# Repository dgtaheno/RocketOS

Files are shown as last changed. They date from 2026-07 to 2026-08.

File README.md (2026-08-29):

# RocketOS

ESP32-based flight computer featuring GPS telemetry, barometric altitude estimation, dual temperature sensing, battery monitoring, MAVLink telemetry, autonomous flight event detection, audible event feedback, fault-tolerant SD logging, data-driven flight profile replay testing and serial hardware flight profile replay.

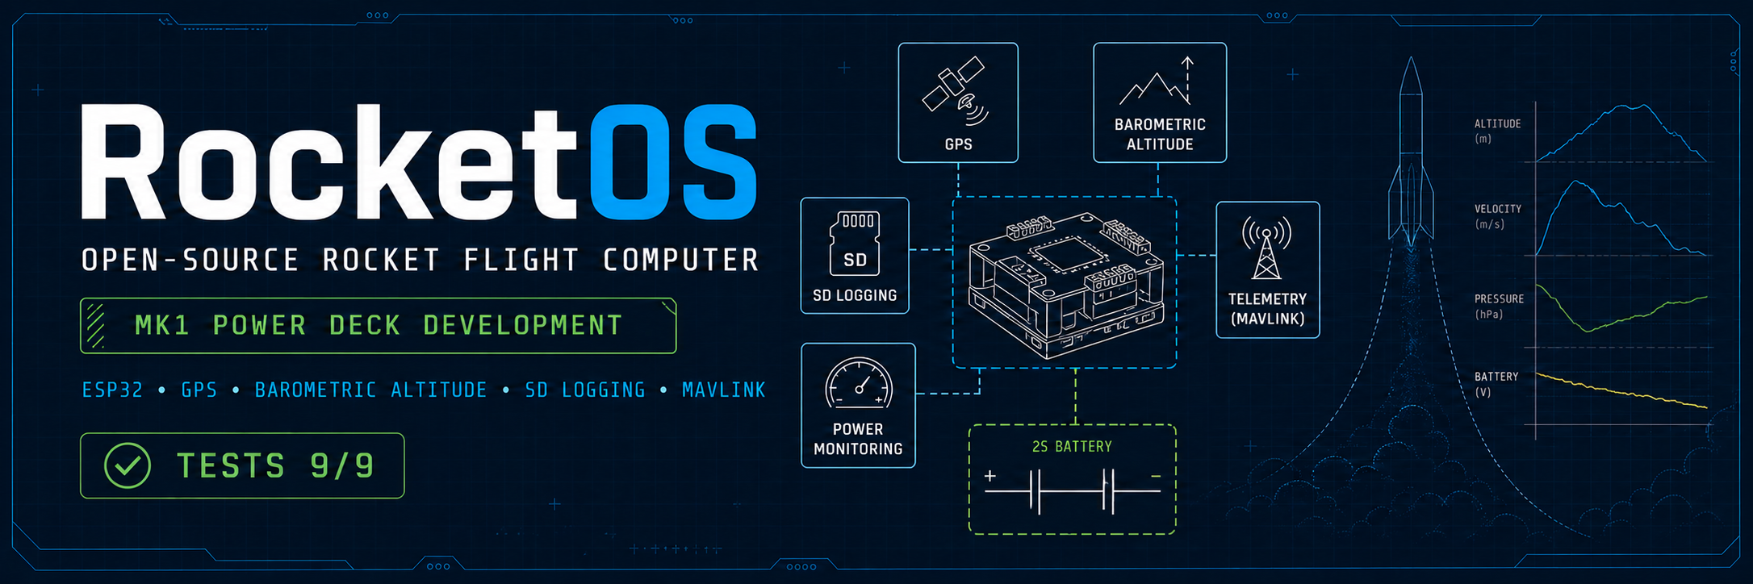
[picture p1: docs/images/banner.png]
Project Banner














---

# Project Status

RocketOS is currently an advanced bench prototype and pre-flight integration platform. The implemented ESP32 DevKitC V4 firmware provides sensing, logging, telemetry, health monitoring, flight-state detection and replay validation.

RocketOS Mk1 targets an ESP32-S3 SuperMini N16R8, a fixed 2S LiPo architecture and a modular deck-based hardware stack for a 54 mm airframe. The Power Deck is under development and has not yet been fabricated or electrically validated.

The current Mk1 development battery is a Tattu 2S 550 mAh LiPo. The firmware BatteryMonitor was migrated from 4S to 2S and bench validated on 2026-08-28.

---

# Real Hardware Prototype

Hardware platform used during validation testing.

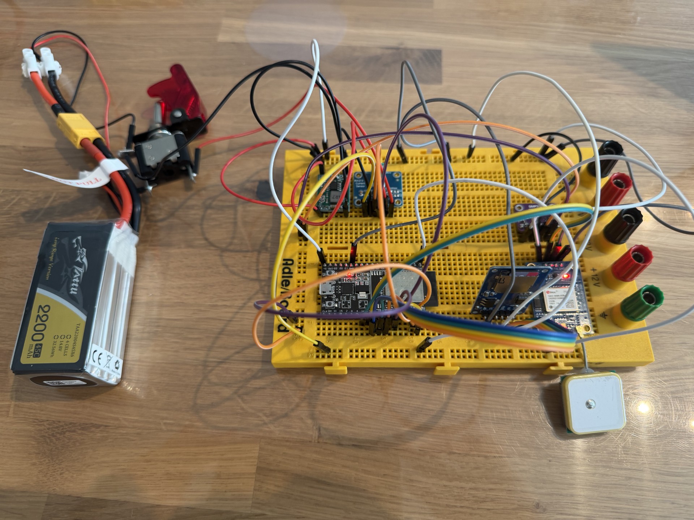
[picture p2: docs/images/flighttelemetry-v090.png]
Flight Telemetry Prototype


---

# Hardware

| Component | Model | Function |
|---|---|---|
| Microcontroller | ESP32 DevKitC V4 | Flight computer |
| GNSS Receiver | u-blox NEO-M9N | Position, altitude, UTC time |
| Barometric Sensor | BMP388 | Pressure, temperature, relative altitude |
| External Thermometer | DS18B20 | Ambient outside temperature |
| Power Monitor | INA219 | Voltage, current, power |
| Storage | MicroSD Module | Flight data logging |
| Audible Feedback | Active Buzzer | Event feedback and recovery beacon |
| Power Supply | MP1584 Buck Converter | Regulated 5 V rail |
| Battery | Tattu LiPo 2S 550 mAh | Current Mk1 development battery |

<table>
  <tr>
    <td align="center"><br><b>NEO-M9N</b></td>
    <td align="center"><br><b>BMP388</b></td>
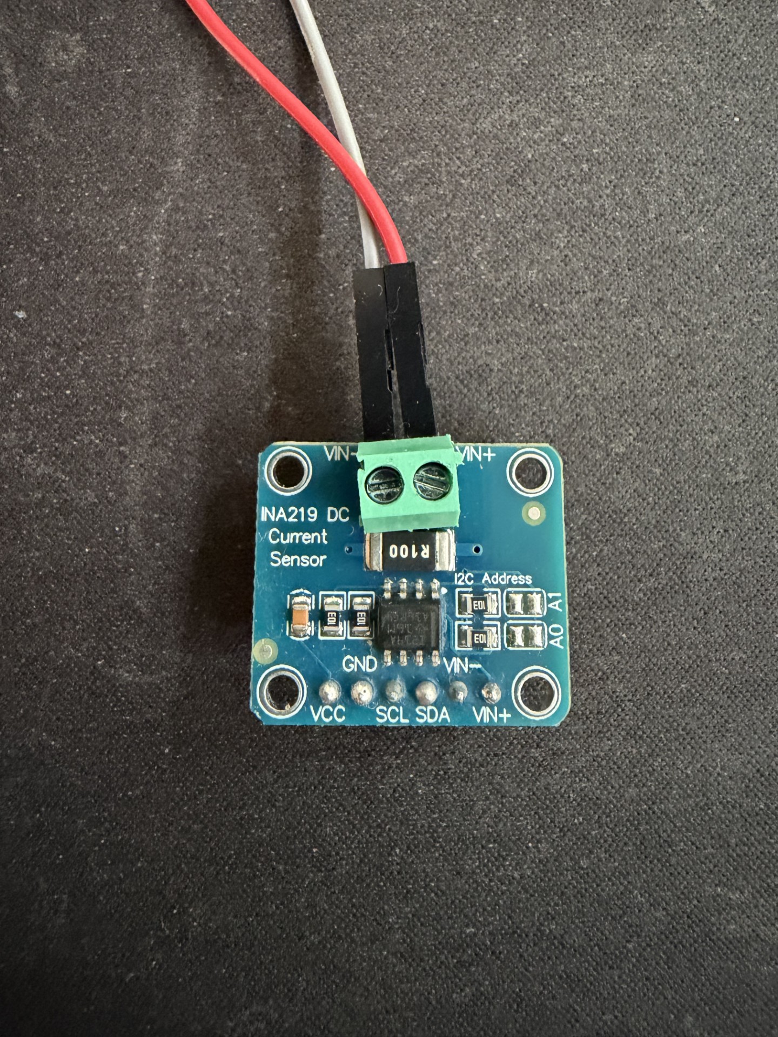
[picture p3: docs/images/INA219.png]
    <td align="center"><br><b>INA219</b></td>
  </tr>
  <tr>
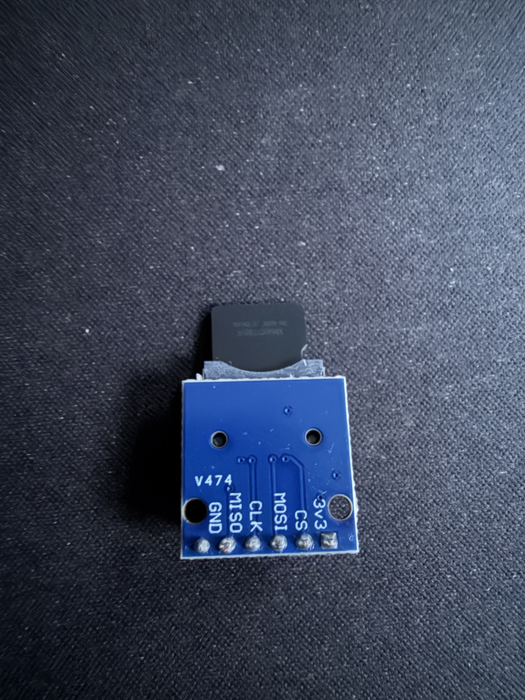
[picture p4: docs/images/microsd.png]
    <td align="center"><br><b>MicroSD</b></td>
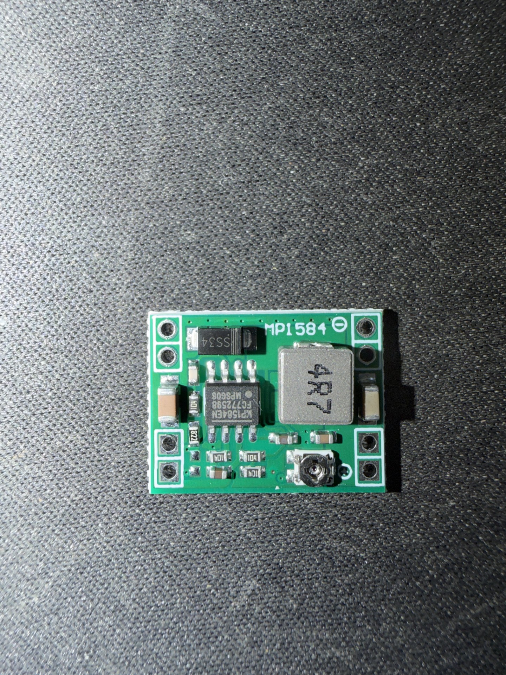
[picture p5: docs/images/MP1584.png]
    <td align="center"><br><b>MP1584</b></td>
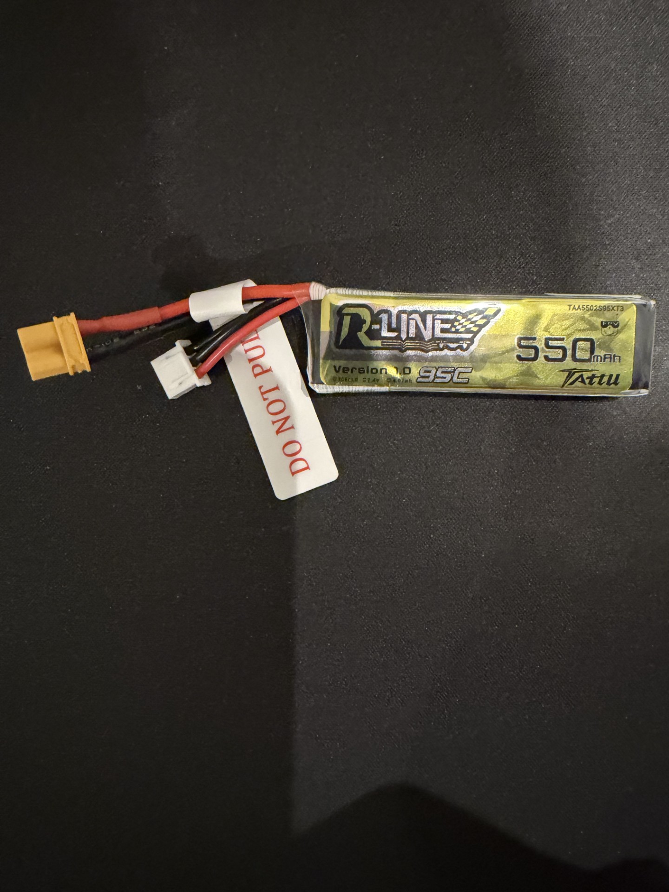
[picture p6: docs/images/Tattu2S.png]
    <td align="center"><br><b>LiPo 2S Tattu 550 mAh</b></td>
  </tr>
  <tr>
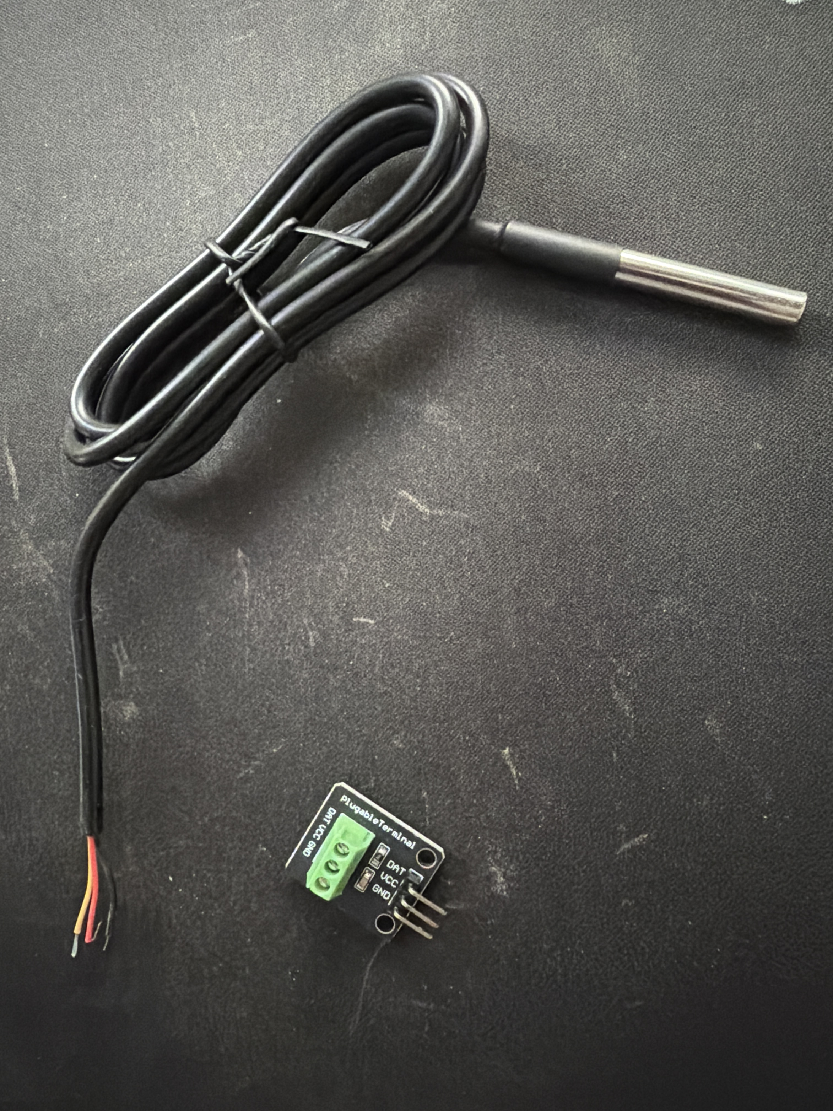
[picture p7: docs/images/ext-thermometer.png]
    <td align="center"><br><b>DS18B20</b></td>
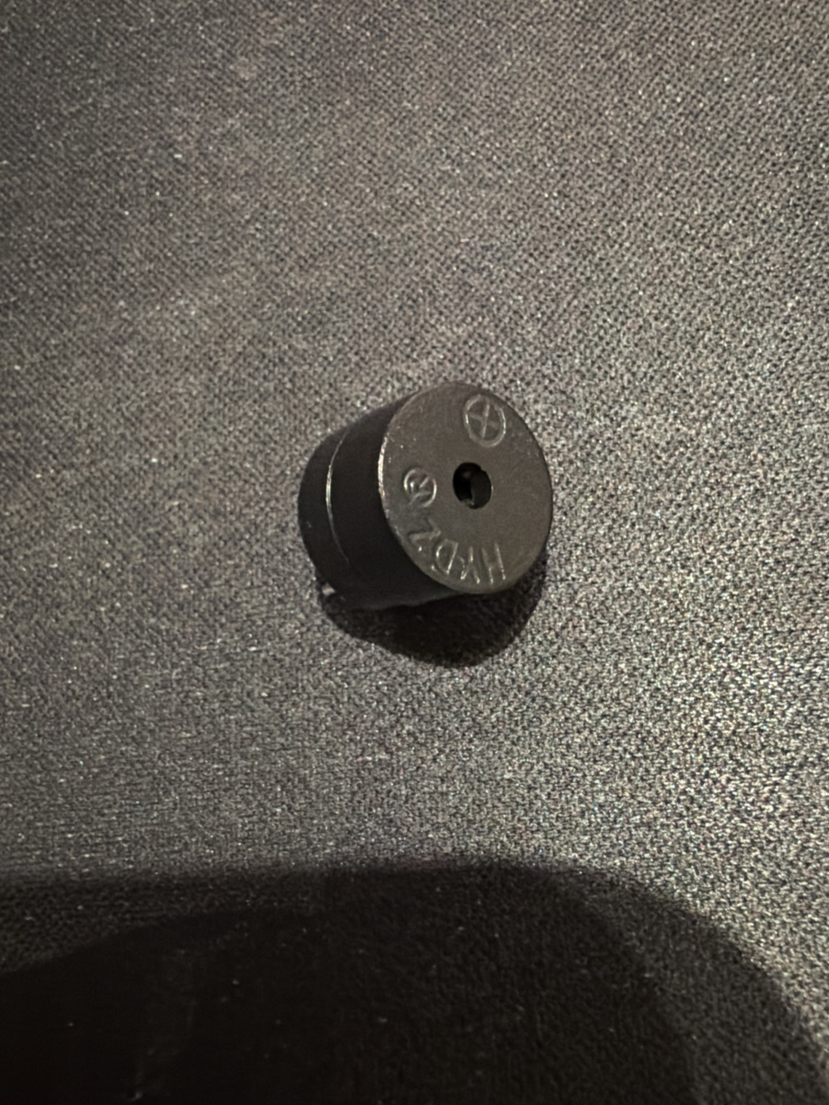
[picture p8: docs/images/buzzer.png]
    <td align="center"><br><b>Active Buzzer</b></td>
    <td></td>
  </tr>
</table>

---

# Overview

RocketOS is a modular open-source flight computer, telemetry, data-logging, validation and post-flight analysis ecosystem for experimental model rocketry.

The project combines:

- GPS telemetry
- Barometric altitude estimation
- Dual temperature sensing with BMP388 and DS18B20
- Battery and power monitoring
- MAVLink telemetry
- QGroundControl interoperability
- Autonomous flight event detection
- Audible event feedback and recovery beacon
- Runtime health monitoring
- Event-driven diagnostics
- Fault-tolerant SD logging
- Buffered telemetry recovery
- Unit tests for core flight logic
- CSV-based flight profile replay tests
- Serial hardware flight profile replay on ESP32
- OpenRocket and generic CSV import tooling

The validation status of each subsystem is documented separately. Flight-profile replay tests run both on the host computer through the PlatformIO native environment and on the ESP32 through USB serial replay. This evidence does not establish that the complete RocketOS Mk1 hardware stack is flight validated.

---

# Scope

This flight computer targets model rocketry.

The flight state machine models a ballistic rocket flight profile with parachute recovery: powered boost, unpowered coast, a single apogee, and descent under recovery. Powered controlled vehicles such as multirotors or fixed-wing aircraft are out of scope by design.

---

# Flight Event Detection

An autonomous flight state machine detects the phases of rocket flight from barometric altitude, independently of GPS fix.

## Flight states

```text
IDLE -> BOOST -> COAST -> APOGEE -> DESCENT -> LANDED
```

| State | Detection |
|---|---|
| IDLE | On the pad, waiting |
| BOOST | Rapid climb above launch threshold |
| COAST | Climb rate stops increasing after boost |
| APOGEE | Climb rate crosses zero at altitude |
| DESCENT | Sustained negative climb rate |
| LANDED | At rest on the ground |

Detection uses BMP388 barometric altitude with low-pass filtered climb rate and multi-sample confirmation to reject sensor noise. Each detected event is reported to the ground station as a MAVLink STATUSTEXT message and signalled audibly through the buzzer.

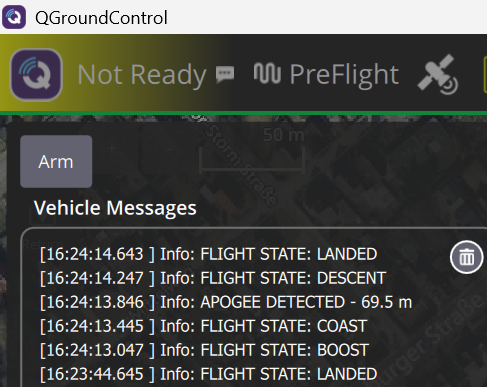
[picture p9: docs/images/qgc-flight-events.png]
Flight Events in QGroundControl


*Flight event sequence reported to QGroundControl via MAVLink STATUSTEXT, including the on-board computed apogee altitude from a synthetic flight profile.*

---

# Flight Profile Replay Testing

Sprint 14 added data-driven replay testing for the flight state machine.

Instead of only testing isolated altitude points, full altitude-vs-time CSV profiles are replayed through the same `FlightStateMachine` logic used by the firmware. The detected apogee is compared against the expected apogee declared in a small `.meta` file.

```text
CSV flight profile -> FlightStateMachine replay -> detected apogee -> expected apogee check
```

## Current replay profiles

| Profile | Description | Expected Apogee | Purpose |
|---|---|---|---|
| `estes_c6` | Small clean flight | 253.9 m | Nominal flight sequence |
| `midpower_machdip` | Mid-power transonic mach-dip case | 904.4 m | False barometric dip rejection |
| `low_apogee` | Low apogee short flight | 71.5 m | Small-flight validation |

The `midpower_machdip` profile includes a synthetic transonic barometric disturbance. The state machine correctly ignores the false dip and detects the real apogee.

## Native test results

```text
RealFlightProfiles/FlightProfileTest.DetectsApogeeWithinTolerance/estes_c6          [PASSED]
RealFlightProfiles/FlightProfileTest.DetectsApogeeWithinTolerance/midpower_machdip  [PASSED]
RealFlightProfiles/FlightProfileTest.DetectsApogeeWithinTolerance/low_apogee        [PASSED]

FlightStateMachine.FullFlightSequence               [PASSED]
FlightStateMachine.IgnoresBarometricNoiseAtIdle     [PASSED]
FlightStateMachine.DoesNotLaunchOnSlowRise          [PASSED]
FlightStateMachine.LaunchesOnFastRise               [PASSED]
FlightStateMachine.ApogeeAltitudeMatchesPeak        [PASSED]
FlightStateMachine.ResetReturnsToIdle               [PASSED]

9 test cases: 9 succeeded
```

Run the test suite with:

```bash
cd firmware/flight-computer
pio test -e native
```

---

# Serial Hardware Flight Profile Replay

Sprint 14b adds a serial hardware replay mode for validating flight profiles on the real ESP32 hardware.

This mode streams a CSV flight profile from the PC to the ESP32 over USB serial. The ESP32 feeds the received altitude samples into the real `FlightStateMachine`, triggering the same flight events used by the firmware.

```text
CSV profile on PC -> USB Serial -> ESP32 -> FlightStateMachine -> buzzer + event output
```

## Purpose

Serial replay bridges the gap between host-based unit tests and real hardware validation.

It validates:

- Flight state detection on the actual ESP32
- Real firmware integration
- Buzzer event feedback
- Serial command handling
- Timing and state transition behaviour with full flight profiles
- Correct handling of long descent profiles

## Protocol

The PC sends:

```text
PROFILE_START
R,<time_ms>,<altitude_m>
R,<time_ms>,<altitude_m>
...
PROFILE_END
```

The ESP32 responds with:

```text
[REPLAY] READY
[REPLAY] START
[FLIGHT] State -> BOOST
[FLIGHT] State -> COAST
[FLIGHT] State -> APOGEE
[FLIGHT] State -> DESCENT
[FLIGHT] State -> LANDED
[REPLAY] END | samples=<count>
```

## Usage

Enable replay mode in `Config.h`:

```cpp
#define SERIAL_PROFILE_REPLAY_MODE 1
#define SERIAL_REPLAY_ALLOW_ACTUATORS 0
#define SERIAL_REPLAY_VERBOSE 0
```

Upload the firmware:

```bash
pio run -e esp32dev -t upload
```

Run a replay profile:

```bash
python tools/send_profile_serial.py test_profiles/low_apogee.csv --port COM5 --speed 1
```

Run the mach-dip profile:

```bash
python tools/send_profile_serial.py test_profiles/midpower_machdip.csv --port COM5 --speed 5
```

Before committing or using the firmware normally, disable replay mode again:

```cpp
#define SERIAL_PROFILE_REPLAY_MODE 0
#define SERIAL_REPLAY_ALLOW_ACTUATORS 0
#define SERIAL_REPLAY_VERBOSE 0
```

## Validated hardware replay profiles

| Profile | Expected Samples | Result |
|---|---|---|
| `low_apogee` | 491 | PASS |
| `midpower_machdip` | 3265 | PASS |

Both profiles replayed successfully on the ESP32 hardware and triggered the full flight sequence:

```text
BOOST -> COAST -> APOGEE -> DESCENT -> LANDED
```

The corrected `midpower_machdip` profile now descends continuously to ground level without the previous artificial altitude drop.

---

# Flight Profile Data Format

Flight profiles are stored under:

```text
firmware/flight-computer/test_profiles/
```

Each profile uses two files:

```text
profile_name.csv   -> time and altitude samples
profile_name.meta  -> expected apogee and tolerance
```

Example CSV:

```csv
time_s,altitude_m
0.05,0.21
0.10,0.64
0.15,1.28
```

Example metadata:

```text
name: Mid-power - transonic mach dip
source: synthetic
expected_apogee_m: 904.4
tolerance_m: 8.0
```

The manifest file controls which profiles are included in the native test run:

```text
estes_c6
midpower_machdip
low_apogee
```

This avoids platform-specific directory scanning and keeps test discovery portable.

---

# Importing New Flight Profiles

A Python import tool is provided under:

```text
firmware/flight-computer/tools/import_profile.py
```

Supported adapters:

| Source | Use case |
|---|---|
| `openrocket` | OpenRocket CSV exports with time and altitude columns |
| `generic` | Generic altimeter or simulator CSV with selectable columns and units |

Example OpenRocket import:

```bash
python tools/import_profile.py --source openrocket exported_flight.csv my_openrocket_flight
```

Example generic import:

```bash
python tools/import_profile.py --source generic altimeter.csv my_real_flight --time-col 0 --alt-col 2 --alt-unit ft --skip-header
```

The importer creates the internal CSV, generates the `.meta` file, calculates expected apogee and updates `manifest.txt`.

---

# Audible Event Feedback

An active buzzer provides distinct rhythmic patterns for system and flight events.

| Event | Pattern |
|---|---|
| Startup | Power-up chime |
| GPS Lock | Ready chirp |
| Launch | Launch tone |
| Apogee | Peak alert with priority |
| Landed | Recovery beacon |
| Battery Critical | Warning stutter |

The buzzer driver is non-blocking. Patterns play in the background using a `millis()`-based state machine, so telemetry, logging and event detection are never stalled by a sound. Flight event sounds do not interrupt each other, except apogee, which has priority.

The landing pattern is a deliberately clear, loud repeating beacon intended to help locate the vehicle on the ground after recovery.

---

# Altitude Reference

Flight altitude is computed from the GPS reference altitude captured on the first GPS fix, plus the barometric change measured since that instant:

```text
flight_altitude = gps_reference_altitude + (bmp_altitude - bmp_altitude_at_fix)
```

This avoids barometric drift accumulated before the fix and keeps flight altitude stable and consistent with the GPS reference at liftoff.

---

# Features

## Flight Event Detection

- Flight State Machine (IDLE -> BOOST -> COAST -> APOGEE -> DESCENT -> LANDED)
- Barometric, GPS-independent detection
- Launch, burnout, apogee, descent and landing detection
- Climb rate estimation with noise rejection
- MAVLink STATUSTEXT event reporting
- Audible event feedback
- Unit-tested and replay-tested flight logic

## Environmental Sensing

- BMP388 pressure measurement
- BMP388 internal temperature
- DS18B20 external ambient temperature
- Relative altitude estimation
- Corrected flight altitude calculation
- Climb rate estimation

## Telemetry

- GPS position
- GPS altitude
- Ground speed
- UTC time synchronization
- GPS timestamped logging
- GPS fix monitoring

## Power Monitoring

- INA219 integration
- Battery voltage monitoring
- Current measurement
- Power consumption monitoring
- Battery SOC estimation
- Battery connection detection
- Battery state monitoring
- Battery event system
- Battery hot-plug detection
- Fixed 2S LiPo monitoring baseline
- Battery disconnected below 5.0 V
- SOC curve from 6.60 V = 0% to 8.40 V = 100%
- Warning threshold at 7.20 V
- Critical threshold at 6.80 V

## Logging

- Automatic CSV logging
- GPS timestamped filenames
- External temperature logging
- Flight state logging
- Buffered logging
- Automatic buffer flush
- FIFO preservation
- SD recovery logging
- Fault-tolerant telemetry storage

## Reliability

- Power-On Self Test (POST)
- Runtime health monitoring
- Fault flags
- Error counters
- Runtime event system
- SD state machine
- SD removal detection
- SD recovery detection

## Testing

- GoogleTest host-based unit tests
- Data-driven flight profile replay tests
- Serial hardware flight profile replay on ESP32
- Synthetic mach-dip validation profile
- Corrected mach-dip descent profile
- OpenRocket/generic CSV import support
- 9 native tests passing

---

# MAVLink Telemetry Stack

| Message | ID | Purpose | Status |
|---|----|---|---|
| HEARTBEAT | 0 | Vehicle presence and link status | Validated |
| SYS_STATUS | 1 | System and battery status | Validated |
| GPS_RAW_INT | 24 | Raw GNSS position and fix type | Validated |
| GLOBAL_POSITION_INT | 33 | Position and relative altitude | Validated |
| GLOBAL_POSITION_INT_COV | 63 | Position with covariance | Validated |
| VFR_HUD | 74 | Ground speed, altitude, climb rate | Validated |
| BATTERY_STATUS | 147 | Battery voltage, current and SOC | Validated |
| HOME_POSITION | 242 | Home reference and distance to home | Validated |
| STATUSTEXT | 253 | Flight event reporting | Validated |

---

# System Architecture

```text
ESP32 DevKitC V4
|
|-- BMP388Sensor
|-- ExternalThermometer (DS18B20)
|-- GPSSensor
|-- INA219Sensor
|-- BatteryMonitor
|-- Buzzer
|-- SDLogger
|-- BufferedLogger
|-- SystemHealth
|-- SystemEvents
|-- MAVLinkTelemetry
|-- FlightStateMachine
|-- FlightSimulator
|-- SerialProfileReplay
|-- Flight Profile Replay Tests
|-- Flight Logger
```

---

# Runtime Event System

```text
SYSTEM_START
SYSTEM_READY

GPS_DETECTED
GPS_FIX_ACQUIRED
GPS_FIX_LOST

SD_DETECTED
SD_REMOVED
SD_INSERTED
SD_RECOVERED

BATTERY_CONNECTED
BATTERY_DISCONNECTED

BATTERY_WARNING
BATTERY_CRITICAL

BUFFER_FLUSH_COMPLETED
```

---

# Generated Telemetry

```text
System Status
GPS Position
GPS Altitude
Flight Altitude
Relative Altitude
Ground Speed
Climb Rate
Flight State
Home Reference
Distance to Home
Internal Temperature (BMP388)
External Temperature (DS18B20)
Battery Voltage
Battery Current
Battery Remaining %
System Health State
```

---

# CSV Log Format

```csv
timestamp_s,
temperature_c,
pressure_hpa,
bmp_altitude_m,
ext_temperature_c,
flight_state,
gps_fix,
latitude,
longitude,
gps_altitude_m,
flight_altitude_m,
speed_kmh,
battery_voltage_v,
current_ma,
power_mw,
battery_soc_percent
```

The `ext_temperature_c` column records external DS18B20 ambient temperature. The `flight_state` column records the detected flight phase for each sample, enabling post-flight analysis of when each event was detected.

---

# Repository Structure

```text
docs/
  TestReport_Sprint8.md
  TestReport_Sprint9.md
  TestReport_Sprint10.md
  TestReport_Sprint11.md
  TestReport_Sprint12.md
  TestReport_Sprint13a.md
  TestReport_Sprint14.md
  TestReport_Sprint14b.md
  images/
  schematics/

firmware/flight-computer/
  include/
  lib/
  src/
  test/
    test_flight_state_machine/
    test_flight_profiles/
  test_profiles/
  tools/
  platformio.ini
```

---

# Validation Status

Repository-reported and bench validation evidence includes:

- GPS validation
- BMP388 validation
- DS18B20 external temperature validation
- SD logging validation
- Buffered logging validation
- FIFO recovery validation
- SD recovery validation
- Runtime health monitoring validation
- Event system validation
- INA219 validation
- Battery voltage validation
- Current measurement validation
- Power monitoring validation
- Battery SOC validation
- Battery event validation
- Battery hot-plug validation
- Buzzer pattern validation
- MAVLink telemetry validation
- Relative altitude validation
- Altitude reference validation
- Climb rate validation
- Distance to home validation
- Flight state machine unit tests
- Flight profile replay tests
- Serial hardware flight profile replay
- Synthetic mach-dip profile validation
- Corrected mach-dip descent validation
- QGroundControl connection validation
- No system regression

## 2S BatteryMonitor Bench Validation

Validated on 2026-08-28 after migration from the historical 4S configuration:

- USB-powered hardware with the LiPo disconnected: 4.10-4.13 V, reported `DISCONNECTED`.
- Connected 2S LiPo: 7.72-7.90 V, reported `CONNECTED` / `OK` with a coherent SOC estimate.
- Battery disconnected threshold: below 5.0 V.
- SOC endpoints: 6.60 V = 0% and 8.40 V = 100%.
- Warning threshold: 7.20 V.
- Critical threshold: 6.80 V.

This validates BatteryMonitor behavior on the current bench prototype. It does not claim that the Power Deck PCB has been fabricated, assembled, brought up or electrically validated.

---

# Current Status

```text
Current Development Stage: RocketOS Mk1 power architecture development
Focus: Power Deck v0.1 schematic and PCB development
Firmware Status: Native tests 9/9 passing + hardware replay validated
Battery Status: Fixed 2S baseline + BatteryMonitor bench validated
Power Deck Status: Under development; not fabricated or electrically validated
```

Current capabilities:

```text
GPS Telemetry
Barometric Altitude Estimation
Dual Temperature Sensing
Climb Rate Estimation
Autonomous Flight Event Detection
Audible Event Feedback
Battery Monitoring
System Health Monitoring
Fault-Tolerant SD Logging
MAVLink Telemetry
Ground Station Instrumentation
Home Reference & Distance to Home
QGroundControl Connectivity
Unit-Tested Flight Logic
CSV Flight Profile Replay Testing
Serial Hardware Flight Profile Replay
OpenRocket / Generic CSV Import Tooling
```

---

# Next Milestones

```text
Complete Power Deck v0.1 schematic
Assign verified physical footprints
Pass KiCad ERC and DRC
Review Power Deck before fabrication
Recovery Deployment Output (servo)
Inertial Measurement Unit (GY-87)
Long-Range Telemetry (LoRa)
Raspberry Pi Ground Station
Field Test Campaign
```

---

# License

MIT License

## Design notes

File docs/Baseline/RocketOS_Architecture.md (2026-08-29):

# RocketOS Architecture

Author: David Garcia-Taheño

Document status: Baseline Reconciled v3

Repository reference:
- Branch: main
- Audited commit: 1b3023f8f2e982317c91b58bc29e1a734755e9d3

## Overview

RocketOS is a modular open-source flight-computer, telemetry, logging, validation, and post-flight analysis ecosystem for experimental model rockets.

The architecture distinguishes between:

- The current development prototype.
- The RocketOS Mk1 target architecture.
- Explicitly planned subsystems.
- Conceptual future functionality.

The current implementation and the target architecture are related but are not identical.

## Architecture Status Convention

Every subsystem in this document must be classified using one of the following states:

### IMPLEMENTED

Repository code exists and provides the described core functionality.

### PARTIALLY IMPLEMENTED

Some core functionality exists, but the target subsystem is incomplete or has not reached its intended final architecture.

### PLANNED

The subsystem is part of the documented roadmap but has no complete implementation in the audited repository.

### CONCEPTUAL

The subsystem or feature is under consideration but is not part of the confirmed baseline.

### DEPRECATED

The subsystem or implementation has been explicitly replaced or retired.

Repository code and validation evidence take precedence when determining implementation status.

The presence of a filename, empty module, roadmap item, schematic, or documentation section does not by itself prove implementation.

## Current Prototype Architecture

The current firmware uses a central Arduino/PlatformIO execution model:

```text
Hardware Drivers
    |
    +-- BMP388
    +-- NEO-M9N GPS
    +-- DS18B20
    +-- INA219
    +-- MicroSD
    +-- Active Buzzer
    |
    v
Acquisition and Derived Values
    |
    +-- Pressure
    +-- Temperature
    +-- Relative Altitude
    +-- GPS Position and Speed
    +-- Battery Voltage, Current and Power
    +-- Battery State
    +-- Climb Rate
    |
    v
Flight Processing and Health
    |
    +-- FlightStateMachine
    +-- SystemHealth
    +-- SystemEvents
    |
    +-------------------------------+
    |                               |
    v                               v
CSV Logging                  MAVLink over USB Serial
    |
    +-- Direct SD Write
    +-- RAM Buffer on Failure
    +-- Ordered Recovery
```

## RocketOS Mk1 Power Architecture

Status: **PARTIALLY IMPLEMENTED**

The RocketOS Mk1 battery architecture is fixed to a 2S LiPo:

- Nominal pack voltage: 7.4 V.
- Maximum charged voltage: 8.4 V.
- Current development battery: Tattu 2S 550 mAh LiPo.

The current firmware BatteryMonitor was migrated from its historical 4S curve to the following 2S baseline:

- Battery disconnected below 5.0 V.
- SOC curve from 6.60 V = 0% to 8.40 V = 100%.
- Warning threshold at 7.20 V.
- Critical threshold at 6.80 V.

Bench validation completed on 2026-08-28:

- LiPo disconnected while powered by USB: 4.10-4.13 V, reported `DISCONNECTED`.
- 2S LiPo connected: 7.72-7.90 V, reported `CONNECTED` / `OK` with a coherent SOC estimate.

This evidence validates the BatteryMonitor behavior on the current bench setup. The Power Deck remains under development; its KiCad files do not demonstrate that a PCB has been fabricated, assembled, brought up, or electrically validated.

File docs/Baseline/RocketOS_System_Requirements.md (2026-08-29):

# RocketOS System Requirements

Author: David Garcia-Taheño

Document status: Baseline Reconciled v3

## Purpose

This document defines the target requirements for RocketOS Mk1.

A documented requirement does not imply implementation.

Implementation status must be determined from:

- Repository code
- Test reports
- Validation records
- Approved decision records

---

# System Mission

RocketOS is an open-source flight computer, telemetry and data logging ecosystem for experimental rockets.

Its primary goals are:

- Reliable flight data acquisition
- Reliable onboard logging
- GPS tracking
- Flight-state detection
- Power monitoring
- Telemetry transmission
- Post-flight analysis
- Hardware and software modularity

---

# Target Platform

## Airframe

Target architecture:

- 54 mm rocket airframe

Status:

- Target defined
- Mechanical validation pending

---

## MCU

Target MCU:

- ESP32-S3 SuperMini N16R8

Status:

- Selected for Mk1
- Migration not yet validated

Current prototype:

- ESP32 DevKitC V4

---

## Power Source

Target power source:

- Fixed 2S LiPo
- 7.4 V nominal
- 8.4 V maximum
- Tattu 2S 550 mAh as the current development battery

Status:

- Selected and baselined for Mk1
- BatteryMonitor bench validated on 2026-08-28
- Complete Mk1 power subsystem validation pending

Historical prototype configurations must not be confused with the Mk1 architecture.

---

# Functional Requirements

## REQ-F-001 Sensor Acquisition

RocketOS shall acquire data from all active baseline sensors.

Current implemented sensors:

- BMP388
- INA219
- DS18B20
- NEO-M9N GPS

Planned:

- GY-87 IMU

Status:

- Partially Implemented

---

## REQ-F-002 Relative Altitude

RocketOS shall calculate relative altitude using barometric data.

Current implementation:

- BMP388
- Boot-relative reference

Status:

- Implemented
- Replay validated

---

## REQ-F-003 Flight-State Detection

RocketOS shall determine the current flight state.

Current implemented states:

- IDLE
- BOOST
- COAST
- APOGEE
- DESCENT
- LANDED

Status:

- Implemented
- Native test validated
- Replay validated

Real flight validation remains pending.

---

## REQ-F-004 Independent Logging

RocketOS shall continue onboard logging even when telemetry is unavailable.

Status:

- Implemented for current MAVLink serial telemetry
- Future LoRa validation pending

---

## REQ-F-005 SD Failure Recovery

RocketOS shall temporarily buffer data when SD storage becomes unavailable.

Current implementation:

- FIFO RAM buffer
- 100 records
- Ordered recovery

Status:

- Implemented

---

## REQ-F-006 Flight Data Recording

RocketOS shall store flight and system data on onboard storage.

Current implementation:

- CSV logging
- Automatic file creation
- GPS timestamp support

Status:

- Implemented

---

## REQ-F-007 Battery Monitoring

RocketOS shall monitor:

- Voltage
- Current
- Power

Current implementation:

- INA219
- Battery disconnected below 5.0 V
- 2S SOC curve: 6.60 V = 0% to 8.40 V = 100%
- Warning threshold: 7.20 V
- Critical threshold: 6.80 V

Status:

- Implemented
- Bench validated on 2026-08-28 after migration from 4S to 2S
- USB-only, LiPo disconnected: 4.10-4.13 V, `DISCONNECTED`
- 2S LiPo connected: 7.72-7.90 V, `CONNECTED` / `OK`

This validation applies to BatteryMonitor behavior on the current bench prototype. It does not establish that the Power Deck PCB has been fabricated or electrically validated.

---

## REQ-F-008 GPS Data

RocketOS shall acquire GPS information when valid GPS data is available.

Current implementation:

- Position
- Altitude
- Speed
- Time and date
- Home reference

Status:

- Implemented

---

## REQ-F-009 Audible Status

RocketOS shall provide audible status information.

Current implementation:

- Active buzzer

Patterns:

- Startup
- GPS lock
- Launch
- Apogee
- Landing
- Critical battery

Status:

- Implemented

---

## REQ-F-010 System Health Monitoring

RocketOS shall monitor subsystem health.

Current implementation:

- Power-on checks
- Health counters
- Event reporting

Status:

- Partially Implemented

---

## REQ-F-011 Telemetry Generation

RocketOS shall generate telemetry messages.

Current implementation:

- MAVLink over USB Serial

Messages:

- HEARTBEAT
- SYS_STATUS
- GPS_RAW_INT
- GLOBAL_POSITION_INT
- GLOBAL_POSITION_INT_COV
- VFR_HUD
- BATTERY_STATUS
- HOME_POSITION
- STATUSTEXT

Status:

- Implemented

---

## REQ-F-012 LoRa Telemetry

RocketOS Mk1 shall support radio telemetry.

Status:

- Planned

Not implemented.

Radio module selection remains open.

---

## REQ-F-013 Ground Station

RocketOS shall provide a dedicated Ground Station.

Status:

- Planned

Not implemented.

---

## REQ-F-014 Flight Analyzer

RocketOS shall support post-flight analysis.

Current support:

- CSV logs
- Replay tools

Dedicated Flight Analyzer:

- Planned

---

## REQ-F-015 Recovery Actuation

RocketOS Mk1 shall support recovery actuation.

Status:

- Planned

Current repository state:

- Placeholder files only

No implementation exists.

---

# Validation Requirements

## REQ-V-001 Native Automated Tests

The flight-state machine shall be testable through native automated tests.

Status:

- Implemented

Repository reports:

- 9 / 9 tests passing

---

## REQ-V-002 Flight Replay Validation

RocketOS shall support replay validation.

Current profiles:

- estes_c6
- low_apogee
- midpower_machdip

Status:

- Implemented

---

## REQ-V-003 Hardware Replay

RocketOS shall support replay execution on physical ESP32 hardware.

Status:

- Implemented

---

## REQ-V-004 Real Flight Validation

RocketOS shall be validated during real rocket flights before being considered flight validated.

Status:

- Pending

---

## REQ-V-005 Validation Before PCB Integration

Subsystems shall be validated before integration into custom PCBs.

Status:

- Active development rule

---

# Non-Functional Requirements

## Reliability

The system shall prioritize reliability over unnecessary complexity.

---

## Modularity

Subsystems should remain replaceable where practical.

---

## Maintainability

The system should remain understandable and maintainable by a hobbyist developer.

---

## Field Repairability

Modules and connections should allow field replacement whenever practical.

---

## Cost Awareness

Avoid unnecessary purchases and unnecessary custom hardware.

---

# Implemented Today

- Sensor acquisition
- Flight-state machine
- GPS
- MAVLink telemetry over USB
- SD logging
- Buffered logging recovery
- Battery monitoring
- Buzzer
- Replay validation
- Native automated tests

# Planned

- LoRa telemetry
- GY-87 integration
- Recovery servo
- Ground Station
- Flight Analyzer
- Real flight campaign

# Open Decisions

- Final LoRa module
- Final telemetry transport architecture
- Final power architecture
- Final recovery architecture
- Flight readiness criteria

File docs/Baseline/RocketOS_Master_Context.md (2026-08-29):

# RocketOS Master Context

Author: David Garcia-Taheño

Document status: Baseline Reconciled v3

Repository reference:
- Repository: RocketOS
- Branch: main
- Audited commit: 1b3023f8f2e982317c91b58bc29e1a734755e9d3
- Latest release identified during the audit: v0.14.1

## Purpose of This Document

This document provides the concise strategic and technical context required to understand the RocketOS project.

It distinguishes explicitly between:

1. The currently implemented development prototype.
2. The selected RocketOS Mk1 target architecture.
3. Functionality explicitly planned in the roadmap.
4. Conceptual ideas that have not yet been accepted into the project baseline.

Repository code and test evidence take precedence when determining whether functionality is currently implemented.

Target-architecture documentation must not be interpreted as evidence that a subsystem has already been implemented, integrated, or validated.

## Project Definition

RocketOS is an open-source flight-computer, telemetry, data-logging, validation, and post-flight analysis ecosystem for experimental model rockets.

The current repository contains an advanced bench prototype and pre-flight integration platform.

The complete RocketOS ecosystem remains under development.

## Project Objectives

RocketOS is intended to provide:

- Reliable acquisition of flight and system data.
- Reliable onboard data logging.
- Flight-state detection.
- Position and time information through GPS.
- Battery voltage and current monitoring.
- Telemetry of flight and health information.
- Audible system-status indication.
- Repeatable validation using simulated and replayed flight profiles.
- Post-flight data analysis.
- A modular and maintainable hardware and software platform.

## Baseline Layers

### Layer 1: Current Implemented Prototype

The repository currently implements an ESP32-based development prototype with:

- ESP32 DevKitC V4 build target.
- BMP388 barometric pressure and altitude sensor.
- NEO-M9N GPS using NMEA data and TinyGPSPlus.
- MicroSD onboard data logging.
- INA219 voltage, current, and power monitoring.
- DS18B20 external temperature monitoring.
- Active buzzer for audible status.
- MAVLink telemetry over USB Serial.
- Flight-state detection.
- System health monitoring.
- Runtime event monitoring.
- Buffered recovery from temporary SD write failures.
- Flight-profile simulation and serial replay tools.
- Native automated tests for flight-state behavior.
- Hardware replay validation using an ESP32.

The current prototype is best classified as:

**Advanced bench prototype / pre-flight integration stage.**

It is not yet a complete RocketOS Mk1 ecosystem and is not yet a flight-ready recovery computer.

### Layer 2: RocketOS Mk1 Target Architecture

The selected direction for RocketOS Mk1 includes:

- ESP32-S3 SuperMini N16R8 as target MCU.
- Compact architecture intended for a 54 mm airframe.
- Fixed 2S LiPo power source.
- Modular carrier/deck PCB architecture.
- Commercial off-the-shelf modules mounted on carrier or integration PCBs.
- Replaceable subsystems where practical.
- Dedicated radio telemetry.
- Dedicated RocketOS Ground Station.
- Post-flight analysis tools.
- Recovery actuation capability.

Target-architecture items must not be described as implemented unless repository code, hardware files, or validation evidence confirms their status.

### Layer 3: Explicitly Planned Functionality

The repository audit identified the following planned functionality:

- Recovery servo implementation.
- LoRa radio integration.
- Dedicated RocketOS Ground Station.
- Flight Analyzer.
- GY-87 / IMU integration.
- Real-flight validation campaign.
- Complete RocketOS Mk1 ecosystem.

These items are part of the stated development direction but are not implemented in the audited repository unless explicitly stated otherwise.

### Layer 4: Conceptual Functionality

The following ideas may appear in roadmap or design material but are not part of the confirmed Mk1 baseline unless promoted through a documented decision:

- Pyrotechnic deployment outputs.
- MOSFET deployment outputs.
- Dual recovery.
- A compact 38 mm variant.
- Additional sensors.
- Camera trigger.
- Additional payload interfaces.
- Additional recovery channels.

Conceptual items must not be treated as requirements or committed roadmap items without an explicit project decision.

## Design Philosophy

RocketOS follows these principles:

- Prefer commercial off-the-shelf modules whenever practical.
- Validate hardware and software concepts before custom PCB integration.
- Prioritize reliability over unnecessary complexity.
- Prioritize modularity.
- Prioritize maintainability.
- Prioritize field repairability.
- Minimize unnecessary cost.
- Avoid unnecessary hardware purchases.
- Preserve working, validated functionality during migration or redesign.
- Keep core modules replaceable where practical.
- Prefer proven solutions over experimental complexity.
- Separate implemented functionality from planned and conceptual functionality.
- Use repository code and test evidence as the technical source of truth.

## Integration Philosophy

The project currently prioritizes commercial modules mounted on carrier or deck PCBs.

Custom PCBs are primarily intended for:

- Power distribution.
- Connectors.
- Mechanical integration.
- Reliable module interconnection.
- Compact packaging.

A custom PCB should not replace a validated commercial module unless there is a documented technical reason.

Mechanical fit and functional behavior should be validated before committing to a final integrated PCB design.

## Development Preferences

When supporting this project:

- Provide complete files by default when code is requested.
- Do not provide partial snippets unless explicitly requested.
- Preserve existing behavior and backward compatibility where practical.
- Do not propose redesigns without identifying the problem being solved.
- Do not propose hardware purchases unless strongly justified.
- Prioritize validation before optimization.
- Start with the simplest viable solution.
- Clearly justify increases in complexity.
- Distinguish documented facts from assumptions.
- Do not invent missing pin assignments, interfaces, requirements, or validation results.
- Prefer updating existing documentation over creating unnecessary new documents.
- Keep documentation concise and maintainable.

## Current Prototype Hardware

The current repository implementation references:

- ESP32 DevKitC V4.
- BMP388.
- NEO-M9N GPS.
- MicroSD module.
- INA219.
- DS18B20.
- Active buzzer.
- USB Serial connection to the host or ground software.

The current repository documentation also references an MP1584 regulator and a 4S LiPo in the prototype or bench configuration.

This historical prototype power arrangement must not be confused with the Mk1 target architecture.

## RocketOS Mk1 Target Hardware

The current target direction includes:

- ESP32-S3 SuperMini N16R8.
- Fixed 2S LiPo architecture (7.4 V nominal, 8.4 V maximum).
- Tattu 2S 550 mAh LiPo as the current Mk1 development battery.
- Compact modular deck or carrier architecture.
- Power Deck.
- Radio telemetry module.
- Recovery actuator.
- 54 mm integration envelope.

The exact LoRa radio module still requires baseline confirmation.

Earlier documentation mentions an SX1278, while more recent architecture or roadmap material identified during repository analysis refers to an SX1262.

Until the selection is confirmed through a project decision, the authoritative wording is:

- LoRa radio module: target device not yet baselined.

## Current Implemented Firmware Capabilities

The audited repository contains:

- Modular C++ libraries.
- Central Arduino `setup()` and `loop()` control flow.
- Timed execution based on `millis()`.
- BMP388 pressure, temperature, and relative-altitude acquisition.
- GPS parsing and validity handling.
- INA219 voltage, current, and power acquisition.
- Battery state estimation and battery warnings.
- DS18B20 external-temperature acquisition.
- MicroSD CSV logging.
- RAM buffering during temporary SD failures.
- Recovery and ordered flush of buffered records.
- Runtime event logging.
- System health monitoring.
- Audible buzzer patterns.
- Flight-state detection.
- MAVLink message generation over USB Serial.
- Native GoogleTest validation.
- Flight-profile replay.
- Serial profile replay into physical ESP32 hardware.
- OpenRocket and generic CSV profile import tooling.

## Implemented Flight-State Sequence

The audited firmware implements:

- IDLE
- BOOST
- COAST
- APOGEE
- DESCENT
- LANDED

The current implementation uses barometric altitude and derived climb rate.

This functionality is flight-event detection.

It is not guidance, navigation, closed-loop flight control, or recovery deployment control.

## Implemented Logging Behavior

The current firmware includes:

- Automatic CSV log creation.
- GPS-based timestamp filenames when GPS time is available.
- Boot-number filename fallback.
- Sensor and state data records.
- SD startup read/write self-test.
- SD failure detection.
- Temporary RAM buffering.
- Ordered recovery of buffered records.
- Separate runtime event log.

The configured buffer contains 100 records.

The current default logging interval reported by the repository audit is one second.

## Implemented Telemetry Behavior

The current firmware implements MAVLink over USB Serial.

The audited MAVLink wrapper sends:

- HEARTBEAT.
- SYS_STATUS.
- GPS_RAW_INT.
- GLOBAL_POSITION_INT.
- GLOBAL_POSITION_INT_COV.
- VFR_HUD.
- BATTERY_STATUS.
- HOME_POSITION.
- STATUSTEXT.

LoRa transport is not implemented in the audited repository.

MAVLink and LoRa must be treated as separate layers:

- MAVLink message layer: implemented over USB Serial.
- LoRa physical transport: planned.

## Current Validation Status

Repository-reported validation includes:

- Native state-machine tests.
- Full flight-profile replay tests.
- Serial replay into physical ESP32 hardware.
- Full state-sequence observation during replay.
- Validation of low-apogee behavior.
- Validation of a synthetic mid-power Mach-dip profile.
- Repository-reported QGroundControl compatibility.
- Repository-reported INA219 hot-plug behavior.
- BatteryMonitor bench validation on 2026-08-28 after migration from 4S to 2S:
  - USB-powered hardware with the LiPo disconnected measured 4.10-4.13 V and reported `DISCONNECTED`.
  - Connected 2S battery measured 7.72-7.90 V and reported `CONNECTED` / `OK` with a coherent SOC estimate.

The validated Mk1 BatteryMonitor baseline is:

- Battery disconnected below 5.0 V.
- SOC curve from 6.60 V = 0% to 8.40 V = 100%.
- Warning threshold at 7.20 V.
- Critical threshold at 6.80 V.

This validates the BatteryMonitor behavior on the current bench prototype. It does not validate the Power Deck PCB or the complete Mk1 power subsystem.

The repository audit did not independently rerun the tests.

No real rocket flight or deployment test was evidenced in the audited repository.

## Current Hardware Development

The repository contains KiCad work for:

- Power Deck v0.1.

The existence of KiCad files confirms hardware-design activity.

It does not by itself confirm:

- Manufacturing readiness.
- Completed schematic review.
- Completed PCB layout review.
- Released fabrication package.
- Completed BOM.
- Assembly.
- Board bring-up.
- Electrical validation.
- Flight validation.

## Current Development Status

- Strategic project definition: established.
- High-level target architecture: established.
- Prototype firmware: substantially implemented for bench testing.
- Modular firmware structure: implemented.
- BMP388 integration: implemented.
- GPS integration: implemented.
- MicroSD logging: implemented.
- Buffered logging recovery: implemented.
- INA219 integration: implemented in code.
- DS18B20 integration: implemented.
- Buzzer integration: implemented.
- MAVLink over USB Serial: implemented.
- Flight-state detection: implemented.
- Profile replay: implemented.
- Native automated tests: implemented.
- Power subsystem: under refinement.
- Power Deck PCB: under development.
- ESP32-S3 Mk1 migration: not yet confirmed as validated.
- Recovery actuation: not implemented.
- LoRa radio link: not implemented.
- GY-87 / IMU integration: not implemented.
- Dedicated Ground Station: not implemented.
- Flight Analyzer: not implemented.
- Real-flight validation: not completed.

## Known Baseline Issues

The repository audit identified the following items requiring attention:

- `SYSTEM_VERSION` is synchronized with the repository/software release version.
- `INA219_ENABLED` is false, but the INA219 is still initialized and read.
- Multiple feature flags may not consistently enable or disable functionality.
- MAVLink binary data and human-readable diagnostic output share the USB Serial interface.
- `RecoveryServo` source files are placeholders.
- `FlightSimulator` appears implemented but effectively disconnected from the main execution path.
- The detailed Mk1 power-distribution architecture is not settled.
- The final LoRa radio selection is not settled.
- PCB manufacturing readiness is not demonstrated.
- Real-flight validation is pending.

## Authority Rules

When determining project truth, use the following priority:

1. Current repository code at a named commit.
2. Current repository test reports and repeatable test evidence.
3. Approved decision records.
4. Current architecture and requirements documents.
5. Roadmap documentation.
6. Historical sprint material.
7. Unapproved concepts and discussion.

A component name or roadmap entry alone does not prove implementation.

A test report documents reported validation, but independent test evidence should be distinguished from author-reported results.

## Confidentiality and Project Separation

RocketOS is a personal open-source project.

Corporate information, files, emails, requirements, source code, or confidential material from the user's employer must not be introduced into the RocketOS project unless explicitly authorized and relevant.

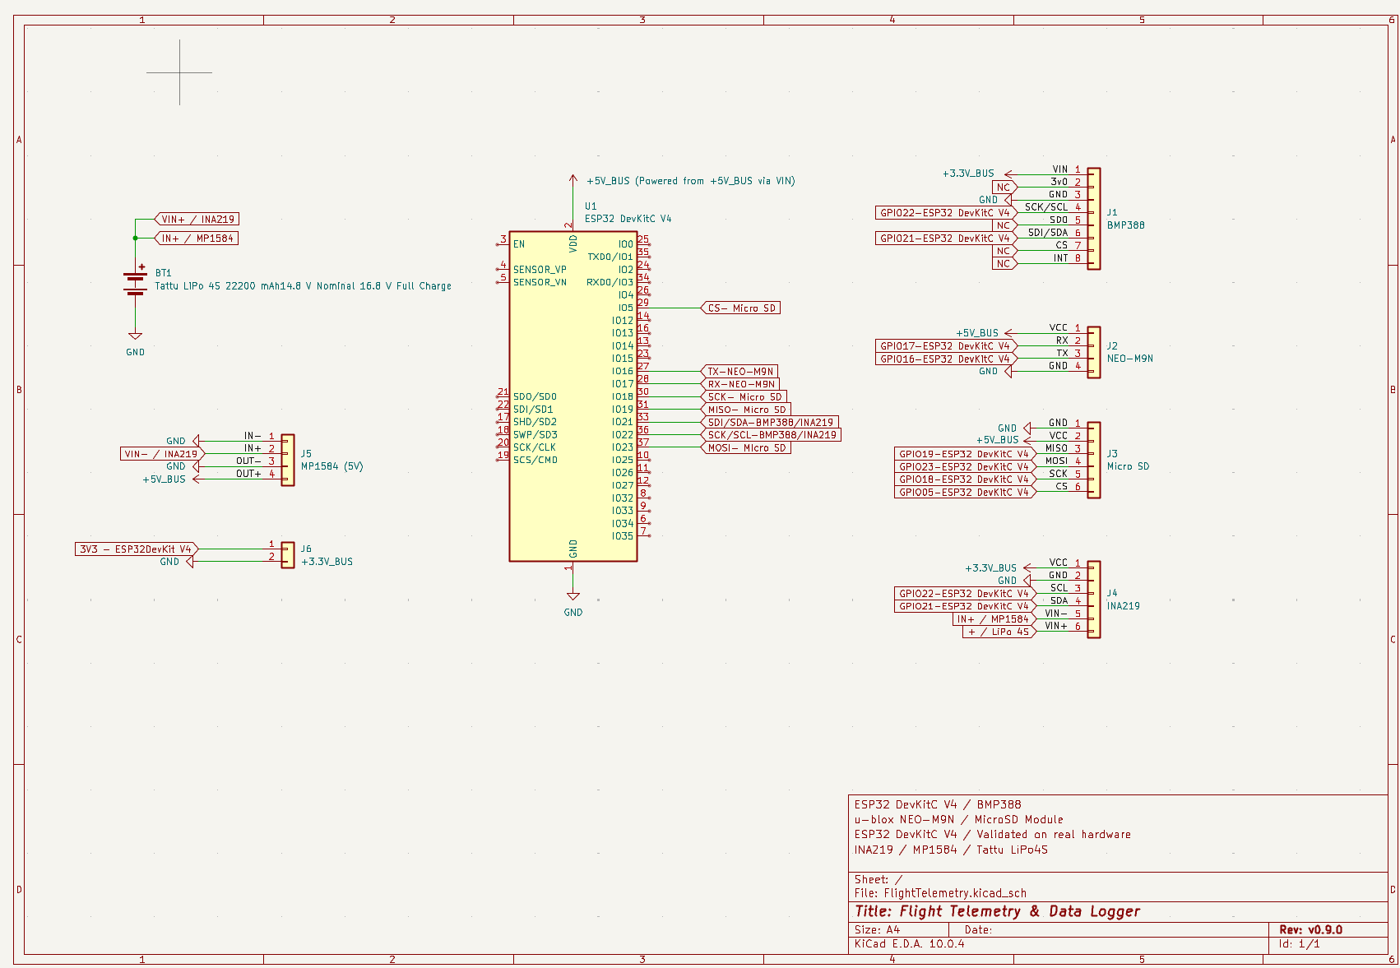
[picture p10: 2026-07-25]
docs/schematics/flighttelemetry-v090.png

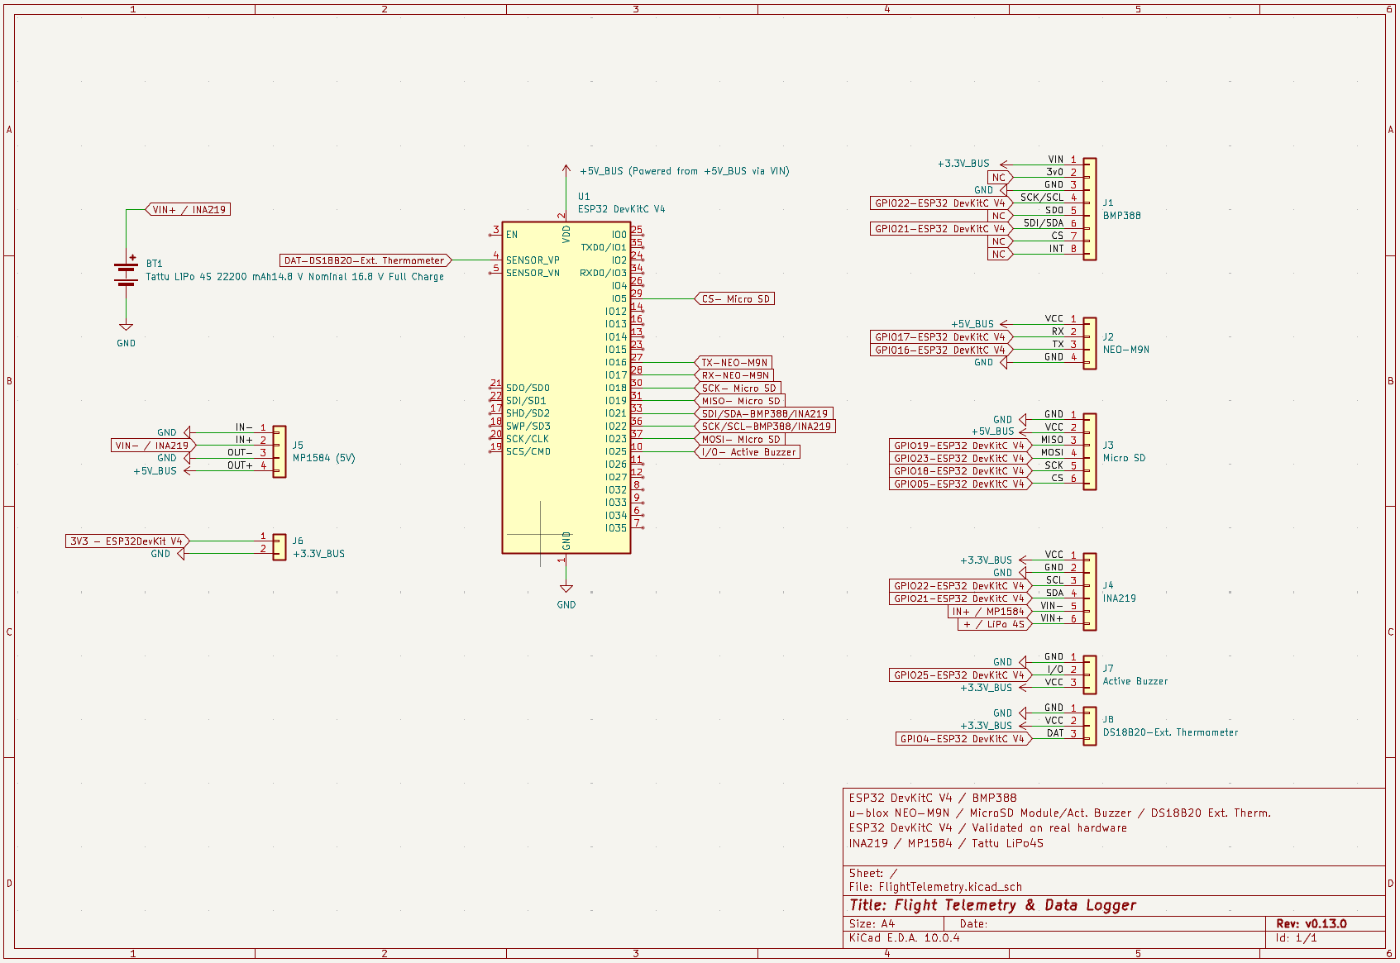
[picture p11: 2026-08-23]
docs/schematics/flighttelemetry-v0130.png

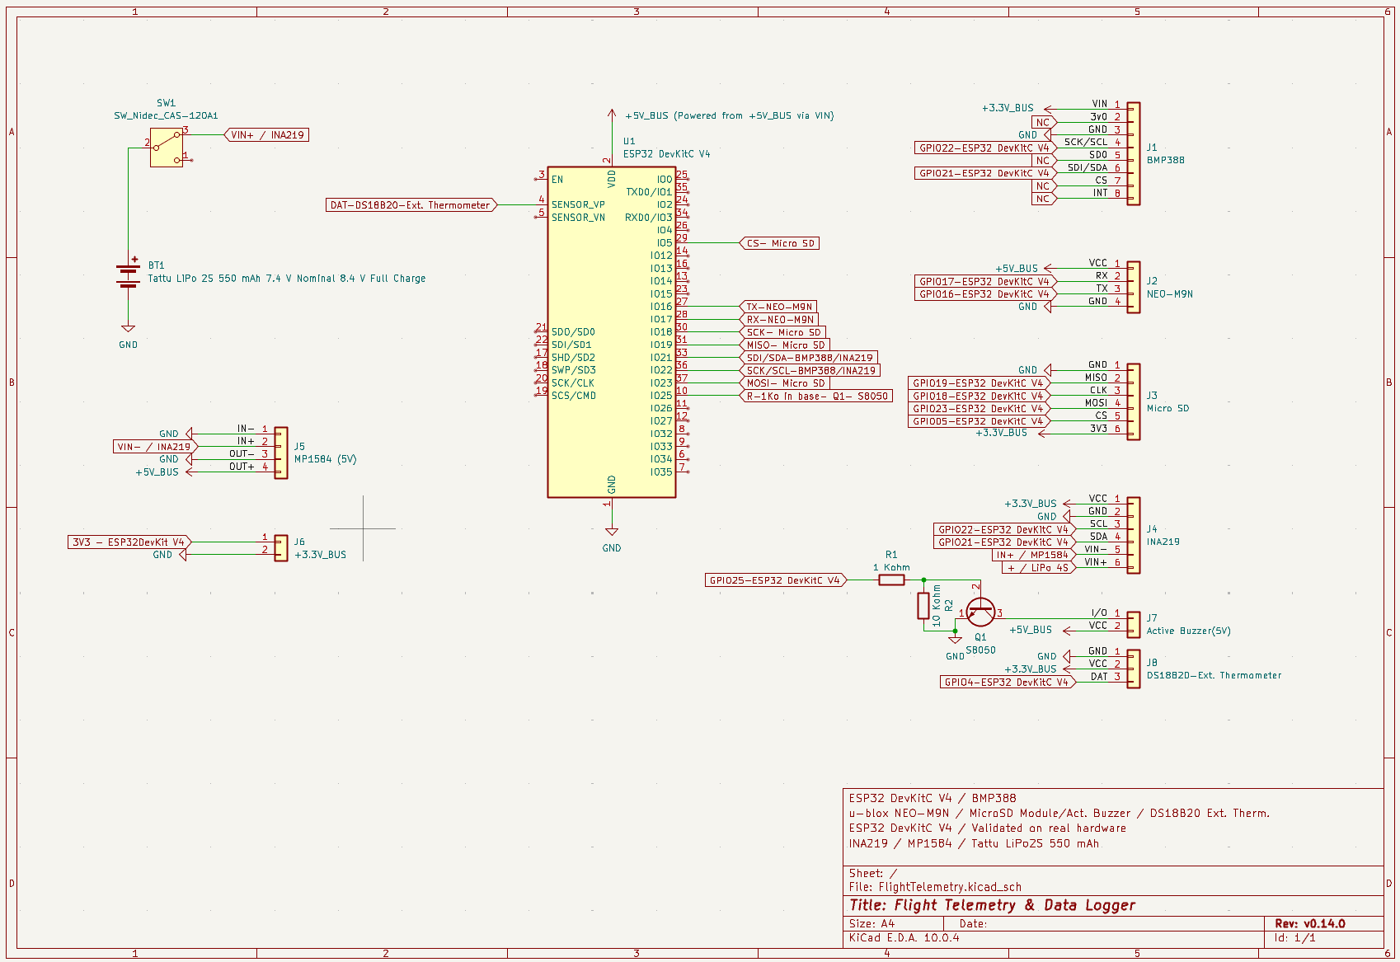
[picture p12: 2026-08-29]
docs/schematics/flighttelemetry-v0140.png

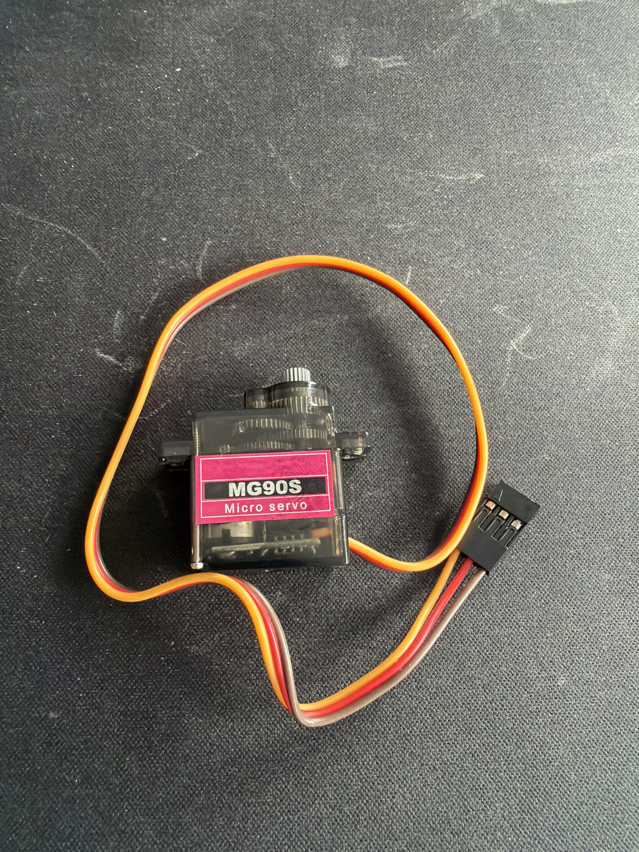
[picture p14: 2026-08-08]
docs/images/servo.png

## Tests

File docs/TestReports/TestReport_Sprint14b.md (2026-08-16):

# TestReport_Sprint14b.md

# Flight Telemetry & Data Logger
## Sprint 14b - Serial Hardware Flight Profile Replay

**Project:** Flight Telemetry & Data Logger  
**Repository:** flight-telemetry-data-logger  
**Sprint:** 14b  
**Release:** v0.14.1  
**Date:** August 2026  
**Author:** David Garcia-Taheño

---

# Objective

The objective of Sprint 14b was to extend the Sprint 14 flight profile replay framework from host-based native tests to real ESP32 hardware.

Sprint 14 validated profiles on the PC using the PlatformIO native environment. Sprint 14b adds a serial hardware replay mode where a PC streams CSV altitude samples to the ESP32 over USB serial, and the actual firmware feeds those samples into the real `FlightStateMachine`.

This provides a hardware-in-the-loop style validation path without requiring a real rocket flight.

---

# Scope

Implemented scope:

- Serial flight profile replay mode
- PC-to-ESP32 CSV streaming tool
- Hardware execution of replay profiles
- Clean serial output mode controlled by `SERIAL_REPLAY_VERBOSE`
- Replay-ready handshake using `[REPLAY] READY`
- MAVLink disabled during serial replay to avoid binary output on the command/debug serial port
- Validation of `low_apogee.csv`
- Validation of corrected `midpower_machdip.csv`

Out of scope:

- Servo or actuator deployment
- MAVLink replay over a separate telemetry port
- SD-based profile replay
- Real launch validation

---

# Architecture

```text
PC CSV profile
      |
      v
send_profile_serial.py
      |
      v
USB Serial
      |
      v
SerialProfileReplay
      |
      v
FlightStateMachine
      |
      v
Flight events + buzzer feedback
```

---

# Serial Protocol

The PC sends:

```text
PROFILE_START
R,<time_ms>,<altitude_m>
R,<time_ms>,<altitude_m>
...
PROFILE_END
```

The ESP32 responds:

```text
[REPLAY] READY
[REPLAY] START
[FLIGHT] State -> BOOST
[FLIGHT] State -> COAST
[FLIGHT] State -> APOGEE
[FLIGHT] State -> DESCENT
[FLIGHT] State -> LANDED
[REPLAY] END | samples=<count>
```

---

# Configuration

Replay mode is controlled from `Config.h`:

```cpp
#define SERIAL_PROFILE_REPLAY_MODE 1
#define SERIAL_REPLAY_ALLOW_ACTUATORS 0
#define SERIAL_REPLAY_VERBOSE 0
```

Before committing or using normal firmware mode, replay is disabled:

```cpp
#define SERIAL_PROFILE_REPLAY_MODE 0
#define SERIAL_REPLAY_ALLOW_ACTUATORS 0
#define SERIAL_REPLAY_VERBOSE 0
```

`SERIAL_REPLAY_ALLOW_ACTUATORS` is reserved for future recovery hardware safety. It remains disabled by default.

---

# Important Fix: Replay Ready Handshake

## Problem

The first version of the Python sender began transmitting when the ESP32 printed:

```text
[INFO] Waiting for PROFILE_START...
```

That message appeared too early, while the ESP32 was still inside `setup()` and not yet processing serial replay samples in `loop()`.

This caused samples to be lost at the beginning of the replay.

Example observed on `low_apogee.csv`:

```text
[REPLAY] END | samples=382
```

The expected number of samples was:

```text
491
```

## Fix

A new replay-ready marker was added at the end of `setup()`:

```cpp
#if SERIAL_PROFILE_REPLAY_MODE

    Serial.println("[REPLAY] READY");

#endif
```

The Python script now waits specifically for:

```text
[REPLAY] READY
```

before sending `PROFILE_START`.

## Result

No samples are lost at the beginning of the replay.

Corrected result:

```text
[REPLAY] END | samples=491
```

---

# Profile Correction: midpower_machdip

## Problem

The original synthetic `midpower_machdip.csv` profile was cut at 120 seconds while the vehicle was still descending at approximately 241 m.

This produced an artificial jump:

```text
240.97 m -> 0.00 m
```

This was not physically valid and made the landing portion unsuitable for validation.

## Fix

The profile was regenerated so that descent continues smoothly to ground level.

Corrected descent excerpt:

```text
t=160.20 s | alt=0.07 m
t=160.25 s | alt=0.00 m
```

The corrected profile contains:

```text
3265 samples
```

---

# Hardware Replay Tests

## Test 1 - low_apogee

Command:

```powershell
python tools\send_profile_serial.py test_profiles\low_apogee.csv --port COM5 --speed 1
```

Result:

```text
[PC] Waiting for ESP32 ready message...
[REPLAY] READY
[PC] ESP32 ready. Starting replay.
[PC] Sending PROFILE_START
[REPLAY] START
[FLIGHT] State -> BOOST
[FLIGHT] State -> COAST
[FLIGHT] State -> APOGEE
[FLIGHT] State -> DESCENT
[FLIGHT] State -> LANDED
[PC] Sending PROFILE_END
[REPLAY] END | samples=491

[PC] Done.
```

Status:

```text
PASS
```

---

## Test 2 - midpower_machdip

Command:

```powershell
python tools\send_profile_serial.py test_profiles\midpower_machdip.csv --port COM5 --speed 5
```

Result:

```text
[PC] Sending PROFILE_START
[REPLAY] START
[FLIGHT] State -> BOOST
[FLIGHT] State -> COAST
[FLIGHT] State -> APOGEE
[FLIGHT] State -> DESCENT
[FLIGHT] State -> LANDED
[PC] Sending PROFILE_END
[REPLAY] END | samples=3265

[PC] Done.
```

Status:

```text
PASS
```

The corrected mach-dip profile replayed completely and triggered the full flight state sequence on the ESP32.

---

# Native Test Regression

After correcting the profile, the native test suite was executed again.

Command:

```powershell
pio test -e native
```

Result:

```text
RealFlightProfiles/FlightProfileTest.DetectsApogeeWithinTolerance/estes_c6          [PASSED]
RealFlightProfiles/FlightProfileTest.DetectsApogeeWithinTolerance/midpower_machdip  [PASSED]
RealFlightProfiles/FlightProfileTest.DetectsApogeeWithinTolerance/low_apogee        [PASSED]

FlightStateMachine.FullFlightSequence              [PASSED]
FlightStateMachine.IgnoresBarometricNoiseAtIdle    [PASSED]
FlightStateMachine.DoesNotLaunchOnSlowRise         [PASSED]
FlightStateMachine.LaunchesOnFastRise              [PASSED]
FlightStateMachine.ApogeeAltitudeMatchesPeak       [PASSED]
FlightStateMachine.ResetReturnsToIdle              [PASSED]

9 test cases: 9 succeeded
```

Status:

```text
PASS
```

---

# Results Summary

| Test | Expected | Actual | Status |
|---|---|---|---|
| `low_apogee` hardware replay | 491 samples | 491 samples | PASS |
| `midpower_machdip` hardware replay | 3265 samples | 3265 samples | PASS |
| Full state sequence on hardware | BOOST -> COAST -> APOGEE -> DESCENT -> LANDED | Detected | PASS |
| Native replay tests | 9 passing | 9 passing | PASS |

---

# Validation Impact

Sprint 14b improves validation depth by adding a third validation layer:

```text
1. Unit-level FSM tests on PC
2. CSV profile replay tests on PC
3. Serial hardware replay on ESP32
```

This makes the project more robust before adding recovery deployment hardware and before attempting real field tests.

---

# Known Limitations

- Serial replay is a bench-testing mode, not a flight mode
- MAVLink is disabled during serial replay because USB Serial is used for replay commands and debug output
- Current replay input uses altitude only
- Real flight validation is still pending
- Servo and other actuators remain disabled during replay by default

---

# Conclusion

Sprint 14b successfully extended the replay testing framework to real ESP32 hardware.

Both `low_apogee` and corrected `midpower_machdip` were streamed over USB serial and replayed successfully by the ESP32. The firmware detected the complete flight sequence in hardware:

```text
BOOST -> COAST -> APOGEE -> DESCENT -> LANDED
```

The corrected mach-dip profile now descends continuously to ground level and remains valid in both native tests and hardware replay.

**Sprint Status:** COMPLETED

**Recommended Release:** v0.14.1

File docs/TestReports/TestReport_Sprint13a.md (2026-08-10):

# TestReport_Sprint13a.md

# Flight Telemetry & Data Logger
## Sprint 13a – Environmental Sensing & Audible Event Feedback

**Project:** Flight Telemetry & Data Logger
**Repository:** flight-telemetry-data-logger
**Sprint:** 13a
**Release:** v0.13.0
**Date:** August 2026
**Author:** David Garcia-Taheño

---

# Objective

The objective of Sprint 13a was to extend the flight computer with environmental
sensing and audible event feedback, and to correct the flight-altitude
reference.

This sprint focused on:

- DS18B20 external ambient thermometer integration
- Active buzzer with a non-blocking driver and distinct event patterns
- Recording the detected flight state in the flight log
- Adding external temperature to the flight log
- Correcting the flight-altitude reference to remove pre-fix barometric drift
- KiCad schematic update to v0.13.0

---

# Hardware Configuration

| Component | Status |
|---|---|
| ESP32 DevKitC V4 | ✅ Operational |
| u-blox NEO-M9N GPS | ✅ Operational |
| BMP388 Barometer | ✅ Operational |
| DS18B20 External Thermometer | ✅ Operational |
| INA219 Current Sensor | ✅ Operational |
| Active Buzzer | ✅ Operational |
| MicroSD Module | ✅ Operational |
| MP1584 Buck Converter | ✅ Operational |
| Tattu 4S LiPo Battery | ✅ Operational |

## Pin Assignment

| Function | Pin |
|---|-----|
| I2C (BMP388, INA219) | GPIO21 / GPIO22 |
| SD SPI (CS) | GPIO5 |
| GPS UART | GPIO16 / GPIO17 |
| Buzzer | GPIO25 |
| DS18B20 (1-Wire) | GPIO4 |

The DS18B20 breakout board includes an onboard 4.7 kOhm pull-up, so no external
pull-up is required. The buzzer and the DS18B20 are both powered from 3.3 V so
their signal pins stay within the ESP32 GPIO range.

---

# Software Configuration

| Component | Version |
|---|---|
| PlatformIO | Latest |
| ESP32 Arduino Framework | Current |
| OneWire | ^2.3.7 |
| DallasTemperature | ^3.11.0 |
| QGroundControl | Installed and validated |
| Firmware Branch | sprint13a-buzzer-thermometer |

---

# Features Implemented

## 1. DS18B20 External Thermometer

### Description

A DS18B20 1-Wire sensor provides ambient (outside) temperature, independent of
the BMP388 internal temperature, which reads higher due to self-heating of the
electronics.

### Behaviour

The sensor is read every 5 seconds, since a 12-bit conversion takes about
750 ms. Ambient temperature changes slowly, so this rate is sufficient and
avoids stalling the main loop.

### Result

✅ External temperature read, shown on serial and logged to CSV

---

## 2. Active Buzzer

### Description

An active buzzer provides audible feedback for flight and system events using
distinct rhythmic patterns. The buzzer is single-tone; character comes from
timing.

### Patterns

| Event | Pattern |
|---|---|
| Startup | Power-up chime |
| GPS Lock | Ready chirp |
| Launch | Launch tone |
| Apogee | Peak alert (priority) |
| Landed | Recovery beacon (repeating) |
| Battery Critical | Warning stutter |

### Non-blocking Driver

The buzzer plays patterns in the background using a `millis()`-based state
machine. No `delay()` is used during flight operation, so telemetry, logging and
event detection are never stalled. The startup fanfare is played to completion
in `setup()`, before the main loop starts, so it is not interrupted by heavy
loop tasks.

Flight event sounds do not interrupt each other; apogee has priority and always
plays. A short silence at the end of each pattern separates consecutive sounds.

### Result

✅ All six patterns validated; startup plays cleanly; sounds do not overlap

---

## 3. Flight State in CSV

### Description

The detected flight state (IDLE, BOOST, COAST, APOGEE, DESCENT, LANDED) is now
recorded for every logged sample, enabling precise post-flight analysis of when
each event was detected relative to the altitude trace.

### Result

✅ `flight_state` column present and correct in the log

---

## 4. Flight Altitude Reference Fix

### Issue

Flight altitude was computed as `gps_reference_altitude + bmp_altitude`, using
the absolute barometric altitude. When the GPS fix was acquired minutes after
boot, the barometer had drifted, and the sum produced incorrect (even negative,
around -36 m) flight altitude values.

### Root Cause

The barometric relative altitude accumulates from boot. Adding it to the GPS
reference captured later mixed two references, carrying the pre-fix drift into
the result.

### Fix

The barometric altitude at the moment of the GPS fix is now captured as an
offset, and flight altitude is computed from the barometric change since then:

```text
flight_altitude = gps_reference_altitude + (bmp_altitude - bmp_altitude_at_fix)
```

The same offset is applied to the MAVLink relative altitude for consistency
between the CSV and the ground station.

### Result

✅ RESOLVED — flight altitude consistent with the GPS reference, no drift

---

# Functional Tests

## Test 1 – Power-On Self Test

### Procedure

Power up and observe POST.

### Expected Result

All subsystems, including the DS18B20, pass initialization.

### Actual Result

✅ PASS

```text
[PASS] BufferedLogger
[PASS] BMP388 sensor
[PASS] INA219 sensor
[PASS] DS18B20 external thermometer
[PASS] SD card
[PASS] GPS receiver
```

---

## Test 2 – External Temperature Reading

### Procedure

Observe external temperature on serial, then hold the probe by hand.

### Expected Result

Stable ambient reading that rises when the probe is warmed and falls when
released.

### Actual Result

✅ PASS

External temperature tracked from ~24 C up to ~29 C when held, and back down
when released, independent of the BMP388 internal temperature.

---

## Test 3 – Buzzer Patterns

### Procedure

Run the dedicated pattern test, which plays all six patterns in a loop.

### Expected Result

Each pattern is audible and distinct, with clear separation.

### Actual Result

✅ PASS

All six patterns played correctly and were distinguishable. The startup pattern
played cleanly (fluid, no stutter) when played to completion before the loop.

---

## Test 4 – Buzzer Non-blocking Behaviour

### Procedure

Run the full firmware and confirm telemetry and logging continue while sounds
play.

### Expected Result

No interruption of telemetry, logging or event detection while the buzzer plays.

### Actual Result

✅ PASS

Startup fanfare and GPS-lock chirp played while telemetry, logging and the state
machine continued without interruption.

---

## Test 5 – Flight State Logging

### Procedure

Inspect the CSV file for the `flight_state` column.

### Expected Result

Each row records the current flight state.

### Actual Result

✅ PASS

`flight_state` recorded as IDLE during ground testing, aligned with the state
machine output.

---

## Test 6 – Flight Altitude Reference

### Procedure

Boot indoors without fix, then acquire GPS fix, and observe flight altitude.

### Expected Result

Flight altitude close to GPS altitude after fix, with no negative jump.

### Actual Result

✅ PASS

```text
GPS Alt    : 42.5 m
Flight Alt : 41.06 m
```

Flight altitude stayed stable around 41 m and consistent with the GPS reference,
more stable than the raw GPS altitude. The previous negative-value behaviour did
not occur.

---

## Test 7 – Continuous Operation

### Procedure

Run the firmware for an extended period.

### Expected Result

Stable operation, no regression.

### Actual Result

✅ PASS

```text
Fault Flags   : 0x00
System Healthy: YES
```

No crashes, brownouts or watchdog resets. Existing telemetry, logging and
fault-tolerance behaviour were unaffected.

---

# Results Summary

| Test | Result |
|---|---|
| Power-On Self Test | ✅ PASS |
| External Temperature Reading | ✅ PASS |
| Buzzer Patterns | ✅ PASS |
| Buzzer Non-blocking Behaviour | ✅ PASS |
| Flight State Logging | ✅ PASS |
| Flight Altitude Reference | ✅ PASS |
| Continuous Operation | ✅ PASS |

---

# CSV Format (16 columns)

```csv
timestamp_s,
temperature_c,
pressure_hpa,
bmp_altitude_m,
ext_temperature_c,
flight_state,
gps_fix,
latitude,
longitude,
gps_altitude_m,
flight_altitude_m,
speed_kmh,
battery_voltage_v,
current_ma,
power_mw,
battery_soc_percent
```

---

# Sprint Achievements

### Completed

- DS18B20 external thermometer integrated (serial + CSV)
- Active buzzer with non-blocking driver and six event patterns
- Startup fanfare played cleanly before the main loop
- Flight event sounds with apogee priority and no overlap
- flight_state recorded in the flight log
- External temperature recorded in the flight log
- Flight altitude reference corrected (no pre-fix drift)
- All audible patterns original with neutral names (no third-party marks)
- KiCad schematic updated to v0.13.0
- README updated
- Release v0.13.0 tagged

### Repository Status

- Build stable
- Environmental sensing operational
- Audible feedback operational
- Flight altitude reference correct
- No regression in existing functionality

---

# Known Limitations

- The DS18B20 conversion takes ~750 ms, so external temperature is sampled every
  5 s; adequate for ambient temperature
- Flight event sounds (launch, apogee, locator) can only be triggered in flight
  or via a lowered-threshold bench demo; they were validated with a dedicated
  pattern test on real hardware
- Field validation with a real launch has not yet been performed

---

# Conclusion

Sprint 13a extended the flight computer with environmental sensing and audible
event feedback, and corrected the flight-altitude reference.

The DS18B20 provides ambient temperature independent of the BMP388 internal
sensor, both logged to the CSV. The active buzzer signals startup, GPS lock,
launch, apogee and a repeating recovery beacon on landing, through a
non-blocking driver that never stalls telemetry or logging. The detected flight
state is now recorded for every sample, and the flight-altitude reference was
corrected so that flight altitude stays consistent with the GPS reference at
liftoff.

All features were validated on real hardware with no regression.

**Sprint Status:** COMPLETED

**Ready for Sprint 13b – Recovery Deployment Output**

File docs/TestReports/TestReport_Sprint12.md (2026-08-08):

# TestReport_Sprint12.md

# Flight Telemetry & Data Logger
## Sprint 12 – Flight Event Detection

**Project:** Flight Telemetry & Data Logger
**Repository:** flight-telemetry-data-logger
**Sprint:** 12
**Release:** v0.12.0
**Date:** August 2026
**Author:** David Garcia-Taheño

---

# Objective

The objective of Sprint 12 was to add autonomous flight event detection to the
Flight Telemetry & Data Logger, transitioning the project from a telemetry
platform into a flight computer capable of recognising the phases of a flight
and reporting them to a Ground Control Station.

This sprint focused on:

- Design of a flight state machine for model rocketry
- Barometric, GPS-independent event detection
- Launch, burnout, apogee, descent and landing detection
- Climb rate estimation with noise rejection
- Unit testing with GoogleTest on the host (native environment)
- Synthetic flight simulation for hardware validation
- MAVLink STATUSTEXT reporting of flight events to QGroundControl

---

# Scope

The flight state machine models a **ballistic flight profile** as used in model
rocketry: powered boost, unpowered coast, a single apogee, and parachute
recovery. It assumes an irreversible trajectory (the vehicle goes up once and
comes down once).

It is **not** intended for powered controlled flight such as multirotors or
fixed-wing aircraft, where altitude changes are arbitrary and repeatable. This
scope is documented in the source and in the README.

---

# Software Configuration

| Component | Version |
|---|---|
| PlatformIO | Latest |
| ESP32 Arduino Framework | Current |
| GoogleTest | 1.17.0 (native environment) |
| Host toolchain | MinGW-w64 GCC 16.1.0 (UCRT64) |
| QGroundControl | Installed and validated |
| Firmware Branch | sprint12-flight-events |

---

# Flight State Machine

## States

```text
IDLE -> BOOST -> COAST -> APOGEE -> DESCENT -> LANDED
```

| State | Meaning | Detection |
|---|---|---|
| IDLE | On the pad, waiting | Altitude stable, no rapid climb |
| BOOST | Motor burning, thrust | Climb rate above launch threshold at altitude |
| COAST | Motor off, rising by inertia | Climb rate stops increasing (burnout) |
| APOGEE | Highest point | Climb rate crosses to zero at altitude |
| DESCENT | Falling under recovery | Sustained negative climb rate |
| LANDED | Back on the ground | Altitude near zero and climb rate near zero |

## Detection thresholds

| Parameter | Value |
|---|---|
| LAUNCH_CLIMB_MS | 5.0 m/s |
| LAUNCH_ALTITUDE_M | 3.0 m |
| APOGEE_MIN_ALTITUDE_M | 5.0 m |
| DESCENT_CLIMB_MS | -2.0 m/s |
| LANDED_ALTITUDE_M | 2.0 m |
| LANDED_CLIMB_MS | 0.5 m/s |

Each transition requires several consecutive confirming samples, and the climb
rate is smoothed with a low-pass filter to reject barometric noise.

## Design notes

- The state machine is fed from the barometric relative altitude, so it operates
  independently of GPS fix. A rocket can lose GPS lock under acceleration; the
  barometer is autonomous and provides fine altitude resolution.
- The class contains no Arduino dependencies (uses `<cstdint>` and `<cmath>` and
  receives time as a parameter), which allows it to compile and run both on the
  ESP32 and on the host for unit testing.

---

# Unit Testing (GoogleTest)

Unit tests run on the host PC through the PlatformIO `native` environment,
independently of the ESP32 hardware.

## Test cases

| Test | Purpose |
|---|---|
| FullFlightSequence | Synthetic flight walks through every state and finishes LANDED |
| IgnoresBarometricNoiseAtIdle | Sensor noise while stationary does not trigger a false launch |
| DoesNotLaunchOnSlowRise | A slow 1 m/s rise (e.g. lifting by hand) does not launch |
| LaunchesOnFastRise | A fast 15 m/s rise leaves IDLE (launch detected) |
| ApogeeAltitudeMatchesPeak | The recorded apogee altitude matches the peak altitude |
| ResetReturnsToIdle | reset() returns the machine to a clean IDLE state |

## Result

```text
FlightStateMachine.FullFlightSequence            [PASSED]
FlightStateMachine.IgnoresBarometricNoiseAtIdle  [PASSED]
FlightStateMachine.DoesNotLaunchOnSlowRise       [PASSED]
FlightStateMachine.LaunchesOnFastRise            [PASSED]
FlightStateMachine.ApogeeAltitudeMatchesPeak     [PASSED]
FlightStateMachine.ResetReturnsToIdle            [PASSED]

6 test cases: 6 succeeded
```

**Status:** All 6 unit tests passing.

---

# Design Finding – Landing Detection

During test development, two design characteristics of the landing detection
were identified and documented.

## Parachute recovery assumption

The landing detection assumes recovery with a parachute. A rocket in a purely
ballistic fall reaches the ground at a high velocity (tens of m/s), which the
logic correctly does not classify as a landing (that is an impact, not a
landing). Landing is confirmed only for a low descent velocity, consistent with
a deployed recovery system.

## Confirmation while at rest

Landing is confirmed with the vehicle at rest on the ground (altitude near zero,
climb rate near zero), not during the descent. Therefore the flight computer must
continue logging after touchdown, allowing the state machine to observe the
resting condition and confirm LANDED.

Both characteristics were reproduced in the unit tests and in the synthetic
flight profile.

---

# Synthetic Flight Simulation

A `FlightSimulator` generates a ballistic flight profile with parachute recovery:

```text
powered boost -> ballistic coast -> apogee -> parachute descent -> resting
```

## Simulation parameters

| Parameter | Value |
|---|---|
| Boost duration | 1.5 s |
| Boost acceleration | 30 m/s^2 |
| Gravity | 9.81 m/s^2 |
| Parachute terminal velocity | 5 m/s |

---

# Functional Tests

## Test 1 – Host Unit Tests

### Procedure

Run `pio test -e native`.

### Expected Result

All GoogleTest cases pass.

### Actual Result

PASS – 6 of 6 test cases succeeded.

---

## Test 2 – Simulation on Hardware

### Procedure

Run the synthetic flight profile through the FlightStateMachine on the ESP32
and observe the state transitions on the serial monitor.

### Expected Result

The full sequence IDLE to LANDED, with a physically sensible apogee.

### Actual Result

PASS

```text
[0.7 s] -> BOOST    | alt = 5.7 m
[2.1 s] -> COAST    | alt = 40.3 m
[4.9 s] -> APOGEE   | alt = 68.4 m
[5.2 s] -> DESCENT  | alt = 66.9 m
        -> LANDED
Apogee altitude : 69.5 m
Final state     : LANDED
```

---

## Test 3 – Real Sensor Robustness

### Procedure

Run the FlightStateMachine fed from the real BMP388 relative altitude while the
prototype is stationary and while being moved slowly by hand.

### Expected Result

No false launch detection.

### Actual Result

PASS

Over several minutes, with the barometer fluctuating within approximately
plus or minus 0.3 m and the prototype being handled, the state machine remained
in IDLE. No false positives were observed.

A slow rise of about one metre performed by hand also did not trigger a launch,
confirming that detection requires both altitude and vertical speed
simultaneously.

---

## Test 4 – MAVLink STATUSTEXT Events

### Procedure

Transmit flight events as MAVLink STATUSTEXT and observe them in QGroundControl.

### Expected Result

The flight event sequence appears in the QGroundControl Vehicle Messages panel.

### Actual Result

PASS

```text
Info: FLIGHT STATE: BOOST
Info: FLIGHT STATE: COAST
Info: APOGEE DETECTED - 69.5 m
Info: FLIGHT STATE: DESCENT
Info: FLIGHT STATE: LANDED
```

The apogee altitude computed on board (69.5 m) is reported to the ground station.

---

## Test 5 – Continuous Operation

### Procedure

Run the firmware for an extended period with event detection active.

### Expected Result

Stable operation, no regression in existing telemetry or logging.

### Actual Result

PASS

```text
Fault Flags   : 0x00
System Healthy: YES
```

No crashes, brownouts or watchdog resets observed. Existing telemetry, logging
and fault-tolerance behaviour were unaffected.

---

# Results Summary

| Test | Result |
|---|---|
| Host Unit Tests (GoogleTest) | PASS |
| Simulation on Hardware | PASS |
| Real Sensor Robustness | PASS |
| MAVLink STATUSTEXT Events | PASS |
| Continuous Operation | PASS |

---

# Sprint Achievements

### Completed

- FlightStateMachine designed and implemented
- Barometric, GPS-independent event detection
- Launch, burnout, apogee, descent and landing detection
- Climb rate estimation with low-pass filtering
- 6 GoogleTest unit tests passing on the host
- Host toolchain (MinGW-w64 GCC) and native test environment configured
- FlightSimulator synthetic flight profile
- Simulation validated on ESP32 hardware
- Robustness validated against real BMP388 noise (no false positives)
- MAVLink STATUSTEXT flight events validated in QGroundControl
- Project scope documented as a model rocketry flight computer

### Repository Status

- Build stable
- Event detection operational
- Unit tests passing
- No regression in existing functionality

---

# Known Limitations

- Detection thresholds are fixed and tuned for a small rocket. Adaptive or
  configurable thresholds are not yet implemented.
- The flight state machine targets ballistic recovery flight only. Powered
  controlled vehicles are out of scope by design.
- Field validation with a real launch has not yet been performed; validation to
  date is by unit test, synthetic simulation and bench robustness testing.

---

# Conclusion

Sprint 12 added autonomous flight event detection to the Flight Telemetry & Data
Logger, implemented as a barometric, GPS-independent state machine covering
launch, burnout, apogee, descent and landing.

The detection logic is covered by six GoogleTest unit tests running on the host,
validated in a synthetic flight simulation on the ESP32 (apogee 69.5 m), and
shown to be robust against real BMP388 sensor noise with no false positives.
Flight events are reported to QGroundControl as MAVLink STATUSTEXT messages,
including the on-board computed apogee altitude.

With this sprint, the project evolves from a MAVLink telemetry platform into a
flight computer with autonomous flight phase detection, backed by unit tests.

**Sprint Status:** COMPLETED

**Ready for Sprint 13 – Recovery Deployment Output**

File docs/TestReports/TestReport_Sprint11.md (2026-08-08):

# TestReport_Sprint11.md

# Flight Telemetry & Data Logger
## Sprint 11 – MAVLink Integration, QGroundControl Validation & Flight Instrumentation

**Project:** Flight Telemetry & Data Logger  
**Repository:** flight-telemetry-data-logger  
**Sprint:** 11 (including 11.2, 11.3, 11.3.1, 11.4 and 11.6)  
**Release:** v0.11.0 / v0.11.1 / v0.11.2  
**Date:** July–August 2026  
**Author:** David Garcia-Taheño

---

# Objective

The objective of Sprint 11 was to complete the MAVLink telemetry implementation and validate interoperability between the Flight Telemetry & Data Logger and Ground Control Station (GCS) software.

This sprint focused on:

- MAVLink communication stabilization
- HEARTBEAT message transmission
- GPS_RAW_INT implementation
- GLOBAL_POSITION_INT_COV implementation
- GLOBAL_POSITION_INT implementation
- BATTERY_STATUS implementation
- SYS_STATUS implementation
- VFR_HUD implementation
- HOME_POSITION implementation
- Climb rate estimation
- QGroundControl integration and live validation
- Correction of invalid battery pack voltage reporting
- Correction of residual ground speed reporting
- Verification of telemetry output through MAVLink streams
- Validation of system compilation and continuous execution

---

# Hardware Configuration

| Component | Status |
|---|---|
| ESP32 DevKitC V4 | ✅ Operational |
| u-blox NEO-M9N GPS | ✅ Operational |
| BMP388 Barometer | ✅ Operational |
| INA219 Current Sensor | ✅ Operational |
| MicroSD Module | ✅ Operational |
| MP1584 Buck Converter | ✅ Operational |
| Tattu 4S LiPo Battery | ✅ Operational |

---

# Software Configuration

| Component | Version |
|---|---|
| PlatformIO | Latest |
| ESP32 Arduino Framework | Current |
| MAVLink C Library | common dialect (includes standard dialect) |
| QGroundControl | Installed and validated |
| Firmware Branches | sprint11-rocket-flight-development, sprint11.4-flight-instrumentation, sprint11.6-home-position |

---

# Features Implemented

## 1. MAVLink HEARTBEAT

### Description

A periodic HEARTBEAT message is transmitted every second.

### Purpose

Allows Ground Control Stations to:

- Detect vehicle presence
- Monitor system status
- Verify link connectivity

### Result

✅ HEARTBEAT messages transmitted successfully

---

## 2. GPS_RAW_INT

### Description

GPS data generated by the NEO-M9N is encoded into MAVLink GPS_RAW_INT messages.

### Parameters Included

- Latitude
- Longitude
- Altitude
- GPS Fix Type
- Ground Speed

### Result

✅ GPS data successfully packed into MAVLink messages

---

## 3. GLOBAL_POSITION_INT_COV

### Description

Vehicle position is exported through GLOBAL_POSITION_INT_COV using the GPS estimator type.

### Parameters Included

- Latitude
- Longitude
- GPS Altitude
- Relative (flight) Altitude
- Velocity components
- Covariance matrix (unknown, NaN)

### Result

✅ Position telemetry successfully generated

---

## 4. GLOBAL_POSITION_INT

### Description

Standard position message consumed by QGroundControl to populate the relative altitude indicator.

### Parameters Included

- Latitude
- Longitude
- GPS Altitude (mm)
- Relative Altitude above home (mm)
- Velocity components (cm/s)
- Heading (unknown, UINT16_MAX)

### Result

✅ Relative altitude successfully displayed in QGroundControl

---

## 5. BATTERY_STATUS

### Description

Battery telemetry measured by the INA219 is encoded into MAVLink BATTERY_STATUS messages.

### Parameters Included

- Pack voltage (cell 1)
- Battery current (centi-amps)
- State of charge (%)
- Battery type (LiPo)
- Battery function (ALL)
- Charge state

### Result

✅ Battery telemetry successfully transmitted and displayed in QGroundControl

---

## 6. SYS_STATUS

### Description

System-level status including battery information is transmitted through SYS_STATUS.

### Parameters Included

- Battery voltage (mV)
- Battery current (centi-amps)
- Battery remaining (%)
- Communication error counters

### Result

✅ SYS_STATUS successfully received by QGroundControl

---

## 7. VFR_HUD

### Description

Flight instrumentation message providing ground station HUD values.

### Parameters Included

- Ground speed (m/s)
- Airspeed (not measured, 0)
- Altitude (m)
- Climb rate (m/s)
- Heading (degrees)
- Throttle (not applicable, 0)

### Climb Rate Estimation

Climb rate is derived from successive barometric altitude samples:

```text
climbRate = (altitude - lastAltitude) / deltaTimeSeconds
```

### Result

✅ Ground speed and climb rate successfully displayed in QGroundControl

---

## 8. HOME_POSITION

### Description

Home reference position consumed by QGroundControl to display the home marker and compute Distance to Home.

### Parameters Included

- Latitude / longitude (first GPS fix position)
- Altitude (GPS reference altitude, MSL)
- Local position x, y, z (0, not used)
- Quaternion (identity: 1, 0, 0, 0)
- Approach vector (0, not used)

### Behaviour

HOME_POSITION is captured and sent once, at the moment of the first GPS fix, reusing the existing GPS reference-altitude capture point. It is then re-emitted every 5 seconds, as some QGroundControl versions request the message periodically.

### Result

✅ Home marker displayed and Distance to Home computed in QGroundControl

---

## 9. Serial MAVLink Stream

### Description

All MAVLink messages are transmitted through the telemetry serial link.

### Result

✅ Stable communication observed

No communication lockups detected.

---

## 10. QGroundControl Integration

### Description

QGroundControl was installed and connected to the ESP32 flight computer over the MAVLink serial link.

### Validated

- Vehicle detection
- GPS position visualization
- Real-time position updates
- Battery telemetry monitoring
- System status monitoring
- Relative altitude instrumentation
- Ground speed instrumentation
- Climb rate instrumentation
- Home marker and Distance to Home

### Result

✅ Vehicle successfully detected and telemetry displayed

---

# Defect Report – BATTERY_STATUS Pack Voltage

## Issue

QGroundControl reported an invalid battery pack voltage of **277.74 V**, while the INA219 measured **15.60 V** on the serial monitor.

State of charge (70 %) was reported correctly, confirming the sensor and battery monitor were functioning as expected.

## Root Cause

The `BATTERY_STATUS.voltages_ext[4]` array was initialized to `UINT16_MAX`.

Per MAVLink specification:

- `voltages[10]` — cells 1 to 10, in mV. Unused cells **must** be `UINT16_MAX`.
- `voltages_ext[4]` — cells 11 to 14, in mV. Unused cells **must** be `0`.

Ground control stations summed the extended cells into the reported pack voltage:

```text
4 x 65535 mV = 262.14 V

262.14 V + 15.60 V = 277.74 V
```

This matched the reported value exactly, confirming the root cause.

## Fix

- `voltages_ext[]` initialized to `0` for all unused cells
- `charge_state` changed from `MAV_BATTERY_CHARGE_STATE_UNDEFINED` to `MAV_BATTERY_CHARGE_STATE_OK` when the battery is connected
- Inline documentation added clarifying the difference between `voltages` and `voltages_ext`

## Verification

| Parameter | Before Fix | After Fix | Serial Reference | Result |
|---|---|---|---|---|
| Pack Voltage | 277.74 V | 15.30 V | 15.30 V | ✅ PASS |
| Remaining | 70 % | 62 % | 62 % | ✅ PASS |
| Charge State | Undefined | Ok | OK | ✅ PASS |

**Defect Status:** ✅ RESOLVED

---

# Defect Report – Relative Altitude Not Displayed

## Issue

QGroundControl reported **0.0 m** relative altitude despite valid barometric and GPS altitude data being available on board and correctly logged to SD.

## Investigation

GLOBAL_POSITION_INT_COV was transmitted instead of GLOBAL_POSITION_INT. QGroundControl populates its relative altitude indicator exclusively from `GLOBAL_POSITION_INT.relative_alt`.

Initial searches for `mavlink_msg_global_position_int.h` within the common dialect returned no results, suggesting an incomplete library installation.

Further analysis showed the message is **not defined in common.xml**. GLOBAL_POSITION_INT (ID 33) belongs to the **standard dialect**, which common.xml includes.

This explains the apparent inconsistency observed during diagnosis:

```text
common.h  MAVLINK_MESSAGE_CRCS   {33, 104, 28, 28, 0, 0, 0}   present
common.h  MAVLINK_MESSAGE_INFO   GLOBAL_POSITION_INT          present
common.h  MAVLINK_MESSAGE_NAMES  { "GLOBAL_POSITION_INT", 33 } present
common/   header file                                         absent
```

The message tables aggregate all messages from included dialects, while the header include resides in the dialect that defines the message.

The header was already available at `lib/MAVLink/standard/`, reachable through common.h line 3230:

```c
#include "../standard/standard.h"
```

## Resolution

No library modification required.

`sendGlobalPositionInt()` was implemented using the existing dialect include chain.

`relative_alt` is populated from the barometric relative altitude rather than absolute altitude, as MAVLink defines this field as height above home, not above mean sea level.

**Defect Status:** ✅ RESOLVED

---

# Defect Report – Residual Ground Speed

## Issue

QGroundControl displayed **0.6 m/s** ground speed while the vehicle was stationary on a workbench.

## Root Cause

The GPS speed deadband defined in `Config.h` was applied only within the logging path. The MAVLink transmission path used raw GPS speed values.

```text
GPS_SPEED_DEADBAND_KMH = 3.0

0.6 m/s = 2.16 km/h  (below threshold, never filtered)
```

## Fix

Deadband applied to the MAVLink transmission path before message encoding, ensuring consistency between logged and transmitted telemetry.

**Defect Status:** ✅ RESOLVED

---

# Sprint 11.6 – HOME_POSITION

## Objective

Transmit HOME_POSITION so QGroundControl can display the home marker and compute Distance to Home.

## Implementation

HOME_POSITION is captured and sent once, at the moment of the first GPS fix, reusing the existing GPS reference-altitude capture point. The home latitude, longitude and reference altitude are stored and re-emitted every 5 seconds, as some QGroundControl versions request the message periodically.

## Message

| Field | Value |
|---|---|
| latitude / longitude | First GPS fix position |
| altitude | GPS reference altitude (MSL) |
| local position (x, y, z) | 0 (not used) |
| quaternion | Identity (1, 0, 0, 0) |
| approach vector | 0 (not used) |

## Validation

Captured on first fix:

```text
[EVENT] GPS_FIX_ACQUIRED
[INFO] GPS reference altitude captured: 9.0 m
===== MAVLINK HOME_POSITION =====
```

QGroundControl result:

| Indicator | Before | After |
|---|---|---|
| Home marker | absent | displayed |
| Distance to Home | --.-- m | 3.6 m |

The 3.6 m reflects GPS drift between the captured home point and the current position while stationary.

**Status:** ✅ RESOLVED

---

# Functional Tests

## Test 1 – Firmware Compilation

### Procedure

Compile complete firmware project.

### Expected Result

Successful build without errors.

### Actual Result

✅ PASS

Project compiled successfully.

---

## Test 2 – Power-On Self Test

### Procedure

Power up ESP32 system and observe POST sequence.

### Expected Result

All subsystems pass initialization.

### Actual Result

✅ PASS

```text
[PASS] BufferedLogger
[PASS] BMP388 sensor
[PASS] INA219 sensor
[PASS] SD card
[PASS] GPS receiver
[PASS] Flight log created

All systems passed
System READY
```

---

## Test 3 – HEARTBEAT Transmission

### Procedure

Monitor MAVLink output.

### Expected Result

HEARTBEAT message every second.

### Actual Result

✅ PASS

Consistent periodic transmission observed.

---

## Test 4 – GPS Acquisition

### Procedure

Wait for GPS lock outdoors with clear sky view.

### Expected Result

Valid GPS fix and stable position.

### Actual Result

✅ PASS

```text
GPS Detected: YES
GPS Fix     : YES
Latitude    : 53.665018
Longitude   : 10.233344
GPS Alt     : 9.0 m
```

Indoor testing produced NO_FIX as expected, due to signal attenuation.

---

## Test 5 – GPS_RAW_INT Generation

### Procedure

Inspect transmitted MAVLink messages.

### Expected Result

GPS position encoded into GPS_RAW_INT.
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

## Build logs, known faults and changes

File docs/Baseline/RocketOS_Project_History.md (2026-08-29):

# RocketOS Project History and Decision Record

Author: David Garcia-Taheño

Document status: Baseline Reconciled v3

Repository reference:
- Branch: main
- Audited commit: 1b3023f8f2e982317c91b58bc29e1a734755e9d3
- Latest release identified during the audit: v0.14.1

## Purpose

This document records major project decisions, the reason behind each decision, and the relationship between the current prototype and the target RocketOS Mk1 architecture.

It is not a chronological transcript of every conversation or sprint.

Its purpose is to preserve the technical and strategic know-how behind the project.

## Decision Status Convention

Each decision may be classified as:

- ACTIVE
- SUPERSEDED
- UNDER REVIEW
- CONCEPTUAL

## Project Origin

RocketOS began as a flight telemetry and data-logging project for experimental model rockets.

The project evolved from an integrated ESP32 development prototype toward a broader modular ecosystem containing:

- Flight computer.
- Sensor acquisition.
- Onboard data logging.
- Flight-state detection.
- GPS.
- Power monitoring.
- Telemetry.
- Ground Station.
- Validation and replay tools.
- Post-flight analysis.
- Future recovery actuation.

## DR-001: Modular Architecture

Status: **ACTIVE**

### Decision

RocketOS shall use a modular hardware and software architecture.

### Reason

- Easier independent validation.
- Easier replacement of failed modules.
- Lower integration risk.
- Improved maintainability.
- Improved field repairability.
- Clearer firmware responsibilities.
- Reduced impact of subsystem changes.

### Current Evidence

The repository contains separate first-party modules for:

- Battery monitoring.
- BMP388.
- Buffered logging.
- Buzzer.
- External thermometer.
- Flight simulation.
- Flight-state machine.
- GPS.
- INA219.
- MAVLink telemetry.
- Recovery servo placeholder.
- SD logging.
- Serial profile replay.
- System events.
- System health.

## DR-002: Commercial Modules First

Status: **ACTIVE**

### Decision

RocketOS shall prioritize commercial off-the-shelf modules before replacing functionality with fully custom circuits.

### Reason

- Faster validation.
- Lower development cost.
- Easier replacement.
- Reduced PCB complexity.
- Reduced risk from unvalidated custom electronics.
- Better suitability for iterative prototyping.

### Consequence

Custom PCBs should initially focus on:

- Power distribution.
- Connectors.
- Mechanical integration.
- Module interconnection.
- Compact mounting.

## DR-003: Validate Before Custom PCB Integration

Status: **ACTIVE**

### Decision

Hardware functionality should be validated before integration into a final custom PCB.

### Reason

Premature integration could commit the project to:

- Incorrect electrical assumptions.
- Incorrect pin assignments.
- Unsuitable modules.
- Mechanical incompatibilities.
- Unnecessary redesigns.
- Additional purchases.

### Consequence

Breadboard and module-level validation remain valid development stages.

Mechanical fit and functional behavior should be confirmed before finalizing integrated PCB designs.

## DR-004: Preserve the Working Prototype

Status: **ACTIVE**

### Decision

The existing ESP32 DevKitC V4 implementation shall be treated as the working development and validation prototype.

### Reason

The prototype already contains implemented and tested value:

- Sensor drivers.
- GPS.
- SD logging.
- Buffered recovery.
- Battery monitoring.
- Buzzer.
- MAVLink.
- Flight-state detection.
- Health monitoring.
- Replay tools.
- Native tests.

Migration to the target Mk1 hardware should preserve this behavior instead of restarting the firmware architecture from zero.

## DR-005: ESP32-S3 SuperMini N16R8 as Target MCU

Status: **ACTIVE TARGET DECISION**

### Decision

ESP32-S3 SuperMini N16R8 is selected as the target MCU for RocketOS Mk1.

### Reason

The recorded selection rationale includes:

- Cost/performance balance.
- 16 MB Flash.
- 8 MB PSRAM.
- Suitable ecosystem support.
- Sufficient expected capability for RocketOS.
- Compact form factor.

### Validation Status

- Decision record: present.
- Rationale: present.
- Migration validation in the audited repository: not confirmed.
- Final pin mapping: not confirmed.
- Final peripheral-allocation validation: not confirmed.

### Consequence

The current DevKitC prototype and the Mk1 target MCU must be documented separately.

The target selection must not be rewritten as already validated hardware.

## DR-006: Prototype and Mk1 Baseline Separation

Status: **ACTIVE**

### Decision

Project documentation shall distinguish between:

1. Current implemented prototype.
2. RocketOS Mk1 target architecture.
3. Planned roadmap.
4. Conceptual future ideas.

### Reason

Earlier documentation could be interpreted as if target components and planned subsystems were already implemented.

The repository audit demonstrated that this was not always the case.

### Consequence

All significant subsystems should be classified as:

- IMPLEMENTED.
- PARTIALLY IMPLEMENTED.
- PLANNED.
- CONCEPTUAL.
- DEPRECATED.

## DR-007: 54 mm Target Architecture

Status: **ACTIVE TARGET DECISION**

### Decision

RocketOS Mk1 shall target a compact architecture suitable for a 54 mm airframe class.

### Reason

The target supports a standardized compact avionics stack for the intended model-rocket platform.

### Validation Status

- Target documented.
- Complete mechanical envelope not yet defined.
- Final PCB dimensions not yet validated.
- Complete stack fit not yet validated in the reconciled baseline.

## DR-008: Fixed 2S LiPo Power Source

Status: **ACTIVE TARGET DECISION**

### Decision

RocketOS Mk1 shall operate from a fixed 2S LiPo battery architecture.

The Tattu 2S 550 mAh LiPo is the current Mk1 development battery. This records the development pack in use without preventing a later capacity change within the fixed 2S architecture if power-budget or endurance testing requires it.

### Context

The current or historical prototype documentation references:

- Tattu 4S LiPo.
- MP1584 regulator.

The historical 4S prototype arrangement is superseded for Mk1 battery monitoring and must not be treated as the current battery baseline.

### Validation Status

- 2S battery architecture selected and fixed for Mk1.
- Current development battery recorded as Tattu 2S 550 mAh.
- BatteryMonitor migrated from 4S to 2S and bench validated on 2026-08-28.
- USB-only with LiPo disconnected measured 4.10-4.13 V and reported `DISCONNECTED`.
- Connected 2S battery measured 7.72-7.90 V and reported `CONNECTED` / `OK` with a coherent SOC estimate.
- Disconnected threshold: below 5.0 V.
- SOC endpoints: 6.60 V = 0% and 8.40 V = 100%.
- Warning threshold: 7.20 V.
- Critical threshold: 6.80 V.
- Final regulators not baselined here.
- Final rail architecture not baselined here.
- Final power budget not documented here.
- Complete Mk1 electrical validation pending.

The 2026-08-28 evidence validates BatteryMonitor behavior on the current bench prototype only. It does not claim that the Power Deck PCB has been fabricated, assembled, brought up, or electrically validated.

## DR-009: Power Deck Strategy

Status: **ACTIVE**

### Decision

A dedicated Power Deck shall be used to develop the target power distribution and integration architecture.

### Reason

- Separate power development from the core flight-computer logic.
- Improve modularity.
- Improve connector reliability.
- Support compact integration.
- Allow the power architecture to evolve without redesigning every subsystem.

### Current Evidence

The repository contains Power Deck v0.1 KiCad files.

### Validation Status

The available repository evidence does not yet confirm:

- Fabrication release.
- Final BOM.
- Assembly.
- Board bring-up.
- Electrical validation.
- Flight validation.

## DR-010: Onboard Logging Independent of Telemetry

Status: **ACTIVE AND IMPLEMENTED FOR CURRENT SERIAL TELEMETRY**

### Decision

Temporary loss of telemetry shall not stop onboard logging.

### Reason

- The radio or external link may fail during flight.
- Onboard data remains necessary for post-flight analysis.
- Logging and telemetry have different reliability dependencies.

### Current Implementation

- MicroSD CSV logging.
- Direct write attempts.
- RAM FIFO on failed writes.
- Ordered recovery after storage returns.

### Future Validation

Behavior under future LoRa link loss remains to be validated after LoRa integration.

## DR-011: Buffered Logging Recovery

Status: **ACTIVE AND IMPLEMENTED**

### Decision

RocketOS shall buffer records in RAM during temporary SD write failures.

### Reason

- Temporary card problems should not immediately discard current data.
- Ordered recovery improves completeness of the recorded flight.

### Current Implementation

- 100-record FIFO.
- Ordered buffer flush.
- Current default logging interval reported as one second.

### Open Points

- Required minimum protected duration.
- Full-buffer behavior.
- Power-loss behavior with buffered records.
- Long-term repeated-failure behavior.

## DR-012: Flight-State Machine

Status: **ACTIVE AND IMPLEMENTED**

### Decision

RocketOS shall use an explicit flight-state machine.

### Current Implemented States

- IDLE.
- BOOST.
- COAST.
- APOGEE.
- DESCENT.
- LANDED.

### Reason

- Provide deterministic flight-event interpretation.
- Support flight logging.
- Support audible events.
- Support telemetry state reporting.
- Provide a foundation for future recovery logic.

### Validation Status

- Native tests reported.
- Profile replay reported.
- Physical ESP32 replay reported.
- Real-flight validation pending.

## DR-013: Validation Through Flight-Profile Replay

Status: **ACTIVE AND IMPLEMENTED**

### Decision

RocketOS shall support repeatable testing using flight profiles.

### Reason

- Test state transitions without requiring repeated launches.
- Reproduce failure cases.
- Compare algorithms consistently.
- Validate low-apogee behavior.
- Validate response to Mach-related pressure disturbances.
- Reuse real or externally supplied profiles in the future.

### Current Implementation

- Native GoogleTest.
- CSV flight profiles.
- Metadata with expected values.
- OpenRocket and generic CSV importer.
- Serial profile sender.
- Replay into physical ESP32.

### Known Limitations

Current replay does not comprehensively reproduce:

- Vibration.
- Acceleration.
- Electrical disturbances.
- GPS loss.
- Real sensor noise.
- Timing stalls.
- Full barometric dynamics.
- Real flight environment.

## DR-014: MAVLink as Current Telemetry Message Layer

Status: **ACTIVE AND IMPLEMENTED**

### Decision

The current prototype shall use MAVLink messages for telemetry reporting.

### Reason

- Structured telemetry messages.
- Compatibility with QGroundControl.
- Reuse of established message definitions.
- Suitable foundation for later transport experimentation.

### Current Transport

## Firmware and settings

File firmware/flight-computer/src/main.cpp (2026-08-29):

#include <Arduino.h>
#include <math.h>

#include "Config.h"
#include "BMP388Sensor.h"
#include "SDLogger.h"
#include "GPSSensor.h"
#include "SystemHealth.h"
#include "SystemEvents.h"
#include "BufferedLogger.h"
#include "INA219Sensor.h"
#include "BatteryMonitor.h"
#include "MAVLinkTelemetry.h"
#include "FlightStateMachine.h"
#include "FlightSimulator.h"
#include "ExternalThermometer.h"
#include "Buzzer.h"
#include "SerialProfileReplay.h"

// --------------------------------------------------
// System Modules
// --------------------------------------------------

BMP388Sensor bmp;
SDLogger logger;
GPSSensor gps;
SystemHealth health;
SystemEvents events;
BufferedLogger telemetryBuffer;
INA219Sensor ina219Sensor;
BatteryMonitor batteryMonitor;
MAVLinkTelemetry mavlink;
FlightStateMachine flightState;
ExternalThermometer thermo;
Buzzer buzzer;
SerialProfileReplay serialReplay;

// --------------------------------------------------
// Timing
// --------------------------------------------------

unsigned long lastLog = 0;
unsigned long lastHealthPrint = 0;
unsigned long lastHeartbeat = 0;
bool flightSimDone = false;
unsigned long lastThermoRead = 0;
float externalTemperature = 0.0f;
bool externalTempValid = false;

// --------------------------------------------------
// GPS Altitude Reference
// --------------------------------------------------

bool gpsReferenceCaptured = false;
float gpsReferenceAltitude = 0.0f;
float bmpAltitudeAtReference = 0.0f;

// --------------------------------------------------
// Home Position (MAVLink)
// --------------------------------------------------

double gpsHomeLatitude = 0.0;
double gpsHomeLongitude = 0.0;
bool homePositionSent = false;
unsigned long lastHomePosition = 0;

// --------------------------------------------------
// GPS Health State Tracking
// --------------------------------------------------

bool gpsWarningActive = false;
GpsErrorCode activeGpsWarning = GPS_ERROR_NONE;

// --------------------------------------------------
// Battery Event State Tracking
// --------------------------------------------------

bool batteryPreviouslyConnected = false;

BatteryState previousBatteryState =
    BATTERY_DISCONNECTED;

// --------------------------------------------------
// MAVLink Cached Battery Telemetry
// --------------------------------------------------

float mavBatteryVoltage = 0.0f;
float mavCurrent_mA = 0.0f;
float mavBatterySoc = 0.0f;
bool mavBatteryConnected = false;

// --------------------------------------------------
// SD Runtime State
// --------------------------------------------------

bool sdAvailable = false;

// --------------------------------------------------
// Helper: Write Telemetry Record to SD
// --------------------------------------------------

bool writeTelemetryRecordToSd(
    const TelemetryRecord& record)
{
#if SD_LOGGER_ENABLED

    if (!sdAvailable)
    {
        return false;
    }

    return logger.writeData(
        record.timestamp,
        record.temperature,
        record.pressure,
        record.bmpAltitude,
        record.extTemperature,
        record.flightState,
        record.gpsFix,
        record.latitude,
        record.longitude,
        record.gpsAltitude,
        record.flightAltitude,
        record.speed,
        record.batteryVoltage,
        record.current_mA,
        record.power_mW,
        record.batterySoc);

#else

    (void)record;

    return false;

#endif
}

// --------------------------------------------------
// Helper: Flush Buffered Telemetry Records
// --------------------------------------------------

bool flushBufferedRecords()
{
#if SD_LOGGER_ENABLED

    if (!sdAvailable)
    {
        return false;
    }

    if (telemetryBuffer.isEmpty())
    {
        return true;
    }

    events.logEvent(
        EVENT_BUFFER_FLUSH_STARTED);

    while (!telemetryBuffer.isEmpty())
    {
        TelemetryRecord pendingRecord;

        // Use peek() first to preserve FIFO order.
        // Only remove the record after a successful write.
        if (!telemetryBuffer.peek(pendingRecord))
        {
            return false;
        }

        bool writeOk =
            writeTelemetryRecordToSd(
                pendingRecord);

        events.updateSdState(
            true,
            writeOk,
            logger.isStorageFull());

        if (!writeOk)
        {
            return false;
        }

        TelemetryRecord discardedRecord;

        telemetryBuffer.pop(
            discardedRecord);
    }

    events.logEvent(
        EVENT_BUFFER_FLUSH_COMPLETED);

    return true;

#else

    return false;

#endif
}

// --------------------------------------------------
// Helper: Update SD Health Information
// --------------------------------------------------

void updateSdHealth()
{
#if SD_LOGGER_ENABLED

    if (!sdAvailable)
    {
        health.reportSdFailure(
            SD_ERROR_NOT_INITIALIZED);

        return;
    }

    uint64_t totalBytes =
        logger.getTotalBytes();

    uint64_t usedBytes =
        logger.getUsedBytes();

    if (events.isSdRemoved())
    {
        health.reportSdFailure(
            SD_ERROR_CARD_REMOVED);

        return;
    }

    if (totalBytes == 0)
    {
        health.reportSdFailure(
            SD_ERROR_NOT_INITIALIZED);

        return;
    }

    health.updateSdStorage(
        totalBytes,
        usedBytes);

#else

    // SD logging is intentionally disabled.
    // Do not access the SD driver or report a hardware fault.

#endif
}

// --------------------------------------------------
// Helper: Report GPS Health Without Counter Spam
// --------------------------------------------------

void reportGpsHealth(
    bool gpsDetected,
    bool gpsFix)
{
    if (!gpsDetected)
    {
        if (!gpsWarningActive ||
            activeGpsWarning != GPS_ERROR_NO_DATA)
        {
            health.reportGpsWarning(
                GPS_ERROR_NO_DATA);

            gpsWarningActive = true;
            activeGpsWarning = GPS_ERROR_NO_DATA;
        }

        return;
    }

    if (!gpsFix)
    {
        if (!gpsWarningActive ||
            activeGpsWarning != GPS_ERROR_NO_FIX)
        {
            health.reportGpsWarning(
                GPS_ERROR_NO_FIX);

            gpsWarningActive = true;
            activeGpsWarning = GPS_ERROR_NO_FIX;
        }

        return;
    }

    health.reportGpsOk();

    gpsWarningActive = false;
    activeGpsWarning = GPS_ERROR_NONE;
}

// --------------------------------------------------
// Helper: Update Battery Events Without Spam
// --------------------------------------------------

void updateBatteryEvents()
{
    bool batteryConnected =
        batteryMonitor.isConnected();

    BatteryState currentBatteryState =
        batteryMonitor.getState();

    // --------------------------------------------------
    // Battery connection state changes
    // --------------------------------------------------

    if (!batteryPreviouslyConnected &&
        batteryConnected)
    {
        events.logEvent(
            EVENT_BATTERY_CONNECTED);
    }
    else if (batteryPreviouslyConnected &&
             !batteryConnected)
    {
        events.logEvent(
            EVENT_BATTERY_DISCONNECTED);
    }

    // --------------------------------------------------
    // Battery warning / critical state changes
    // --------------------------------------------------

    if (batteryConnected &&
        currentBatteryState != previousBatteryState)
    {
        if (currentBatteryState == BATTERY_WARNING)
        {
            events.logEvent(
                EVENT_BATTERY_WARNING);
        }
        else if (currentBatteryState == BATTERY_CRITICAL)
        {
            events.logEvent(
                EVENT_BATTERY_CRITICAL);
        }
    }

    batteryPreviouslyConnected =
        batteryConnected;

    previousBatteryState =
        currentBatteryState;
}

// --------------------------------------------------
// Helper: Print System Health Periodically
// --------------------------------------------------

void printHealthIfNeeded()
{
#if PRINT_HEALTH_TO_SERIAL

    if (millis() - lastHealthPrint >= HEALTH_PRINT_INTERVAL_MS)
    {
        lastHealthPrint = millis();

        health.printStatus();

#if SD_LOGGER_ENABLED
        events.printSdState();
#endif

        Serial.println();
        Serial.println("Buffered Logging");
        Serial.println("--------------------------------");

        Serial.print("Buffered Records : ");
        Serial.println(telemetryBuffer.size());

        Serial.print("Buffer Capacity  : ");
        Serial.println(telemetryBuffer.capacity());

        Serial.print("Buffer Free      : ");
        Serial.println(telemetryBuffer.freeSpace());

        Serial.print("Dropped Records  : ");
        Serial.println(telemetryBuffer.getDroppedRecords());

        Serial.print("Total Buffered   : ");
        Serial.println(telemetryBuffer.getTotalBuffered());

        Serial.println("--------------------------------");
        Serial.println();
    }

#endif
}

// --------------------------------------------------
// Helper: Handle Flight State Events
// --------------------------------------------------

void handleFlightStateEvent()
{
    if (!flightState.hasStateChanged())
    {
        return;
    }

    const char* stateName =
        flightState.getStateString();

    Serial.print("[FLIGHT] State -> ");
    Serial.println(stateName);

    char flightMsg[50];

    if (flightState.getState() == FLIGHT_APOGEE)
    {
        snprintf(
            flightMsg,
            sizeof(flightMsg),
            "APOGEE DETECTED - %.1f m",
            flightState.getApogeeAltitude());
    }
    else
    {
        snprintf(
            flightMsg,
            sizeof(flightMsg),
            "FLIGHT STATE: %s",
            stateName);
    }

#if !SERIAL_PROFILE_REPLAY_MODE

    // MAV_SEVERITY_INFO = 6
    mavlink.sendStatusText(
        6,
        flightMsg);

#endif

#if BUZZER_ENABLED

    // Only start a new sound if the buzzer is free,
    // so flight event sounds don't cut each other off.
    // Apogee is critical and always plays.
    if (flightState.getState() == FLIGHT_APOGEE)
    {
        buzzer.play(BUZZER_APOGEE);
    }
    else if (!buzzer.isPlaying())
    {
        switch (flightState.getState())
        {
            case FLIGHT_BOOST:
                buzzer.play(BUZZER_IGNITION);
                break;

            case FLIGHT_LANDED:
                buzzer.startLocator();
                break;

            default:
                break;
        }
    }

#endif
}

// --------------------------------------------------
// Setup
// --------------------------------------------------

void setup()
{
    Serial.begin(115200);

    health.reset();

    events.begin();

#if SERIAL_PROFILE_REPLAY_MODE

    serialReplay.begin(Serial);

    Serial.println("[INFO] Serial profile replay mode enabled");
    Serial.println("[INFO] Waiting for PROFILE_START...");

#endif

    events.logEvent(
        EVENT_SYSTEM_START);

    Serial.println();
    Serial.println("================================");
    Serial.println(SYSTEM_NAME);
    Serial.println("================================");
    Serial.println();

    Serial.println("Running Power-On Self Test (POST)...");
    Serial.println();

    // --------------------------------------------------
    // BufferedLogger Self-Test
    // --------------------------------------------------

    Serial.println("BufferedLogger Self-Test");

    TelemetryRecord test = {};
    test.timestamp = 123;

    if (!telemetryBuffer.push(test))
    {
        Serial.println("[FAIL] BufferedLogger push");
    }
    else
    {
        TelemetryRecord out = {};

        if (!telemetryBuffer.pop(out))
        {
            Serial.println("[FAIL] BufferedLogger pop");
        }
        else if (out.timestamp != 123)
        {
            Serial.println("[FAIL] BufferedLogger FIFO");
        }
        else
        {
            Serial.println("[PASS] BufferedLogger");
        }
    }

    // --------------------------------------------------
    // BMP388
    // --------------------------------------------------

    if (!bmp.begin())
    {
        health.reportBmpFailure(
            BMP_ERROR_READ_FAILED);

        Serial.println("[FAIL] BMP388 sensor not detected");

#if HALT_ON_BMP388_FAIL
        while (1)
        {
            delay(1000);
        }
#endif
    }

    if (!bmp.selfTest())
    {
        health.reportBmpFailure(
            BMP_ERROR_INVALID_DATA);

        Serial.println("[FAIL] BMP388 self-test failed");

#if HALT_ON_BMP388_FAIL
        while (1)
        {
            delay(1000);
        }
#endif
    }

    health.reportBmpOk();

    Serial.println("[PASS] BMP388 sensor");

    // --------------------------------------------------
    // INA219
    // --------------------------------------------------

    if (!ina219Sensor.begin())
    {
        Serial.println("[WARN] INA219 power monitor not detected");
    }

    // --------------------------------------------------
    // External Thermometer (DS18B20)
    // --------------------------------------------------

#if EXT_THERMOMETER_ENABLED

    if (thermo.begin(EXT_THERMOMETER_PIN))
    {
        Serial.println("[PASS] DS18B20 external thermometer");
    }
    else
    {
        Serial.println("[WARN] DS18B20 external thermometer not detected");
    }
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
void loop()
{
#if FLIGHT_SIMULATION_MODE

    // Deferred flight simulation.
    // Runs once, 15 seconds after boot, so QGroundControl has
    // time to connect and receive the STATUSTEXT events.
    static uint32_t lastSimRun = 0;

    if (millis() - lastSimRun > 30000)
    {
        lastSimRun = millis();

        // Existing simulation code unchanged...
    }

#endif

#if BUZZER_ENABLED
    buzzer.update();
#endif

#if SERIAL_PROFILE_REPLAY_MODE

    serialReplay.update();

    while (serialReplay.hasSample())
    {
        SerialReplaySample sample;

        if (serialReplay.popSample(sample))
        {
            flightState.update(
                sample.altitudeM,
                sample.timeMs);

            handleFlightStateEvent();

#if SERIAL_REPLAY_VERBOSE

            Serial.print("[REPLAY] t=");
            Serial.print(sample.timeMs / 1000.0f, 2);
            Serial.print(" s | alt=");
            Serial.print(sample.altitudeM, 2);
            Serial.print(" m | state=");
            Serial.println(flightState.getStateString());

#endif
        }
    }

    return;

#endif

#if GPS_ENABLED
    gps.update();
#endif

    // --------------------------------------------------
    // External Thermometer (read every 5 s, DS18B20 is slow)
    // --------------------------------------------------

#if EXT_THERMOMETER_ENABLED

    if (millis() - lastThermoRead >= 5000)
    {
        lastThermoRead = millis();
        externalTempValid = thermo.update();

        if (externalTempValid)
        {
            externalTemperature = thermo.getTemperature();
        }
    }

#endif

    // --------------------------------------------------
    // MAVLink Periodic Telemetry
    // --------------------------------------------------

    if (millis() - lastHeartbeat >= 1000)
    {
        lastHeartbeat = millis();

#if GPS_ENABLED

        double mavLatitude =
            gps.getLatitude();

        double mavLongitude =
            gps.getLongitude();

        float mavGpsAltitude =
            gps.getAltitude();

        float mavGpsSpeed =
            gps.getSpeed();

        bool mavGpsFix =
            gps.hasFix();

        float mavRelativeAltitude =
            gpsReferenceCaptured
                ? gpsReferenceAltitude +
                    (bmp.getRelativeAltitude() - bmpAltitudeAtReference)
                : mavGpsAltitude;

        // Height above the barometric reference point.
        // MAVLink GLOBAL_POSITION_INT.relative_alt expects
        // altitude above home, not altitude above sea level.
        float mavHeightAboveGround =
            bmp.getRelativeAltitude();

#else

        double mavLatitude = 0.0;
        double mavLongitude = 0.0;

        float mavGpsAltitude = 0.0f;
        float mavGpsSpeed = 0.0f;
        bool mavGpsFix = false;

        float mavRelativeAltitude = 0.0f;
        float mavHeightAboveGround = 0.0f;

#endif

        // GPS speed deadband.
        // Prevents ground station instruments from showing
        // residual speed noise while the vehicle is stationary.
        if (fabs(mavGpsSpeed) < GPS_SPEED_DEADBAND_KMH)
        {
            mavGpsSpeed = 0.0f;
        }

        mavlink.sendHeartbeat();

        mavlink.sendGPSRawInt(
            mavLatitude,
            mavLongitude,
            mavGpsAltitude,
            mavGpsSpeed,
            mavGpsFix);

        mavlink.sendBatteryStatus(
            mavBatteryVoltage,
            mavCurrent_mA,
            mavBatterySoc,
            mavBatteryConnected);

        mavlink.sendGlobalPositionInt(
            mavLatitude,
            mavLongitude,
            mavGpsAltitude,
            mavHeightAboveGround,
            mavGpsSpeed);

        mavlink.sendGlobalPositionIntCov(
            mavLatitude,
            mavLongitude,
            mavGpsAltitude,
            mavRelativeAltitude,
            mavGpsSpeed);

        mavlink.sendSysStatus(
            mavBatteryVoltage,
            mavCurrent_mA,
            mavBatterySoc,
            mavBatteryConnected);

        mavlink.sendVFRHUD(
            mavGpsSpeed,
            mavRelativeAltitude,
            0.0f);

        // Re-emit HOME_POSITION every 5 seconds once captured.
        // Some QGroundControl versions request it periodically.
        if (homePositionSent &&
            millis() - lastHomePosition >= 5000)
        {
            lastHomePosition = millis();

            mavlink.sendHomePosition(
                gpsHomeLatitude,
                gpsHomeLongitude,
                gpsReferenceAltitude);
        }
    }

    if (millis() - lastLog >= LOG_INTERVAL_MS)
    {
        lastLog = millis();

        // --------------------------------------------------
        // BMP388 Update
        // --------------------------------------------------

        if (!bmp.update())
        {
            health.reportBmpFailure(
                BMP_ERROR_READ_FAILED);

            events.updateBmpState(
                false);

            Serial.println("[WARN] BMP388 read error");

            printHealthIfNeeded();

            return;
        }

        health.reportBmpOk();

        events.updateBmpState(
            true);

        float temperature = bmp.getTemperature();
        float pressure = bmp.getPressure();
        float bmpAltitude = bmp.getRelativeAltitude();

        // --------------------------------------------------
        // Flight State Machine (barometric, autonomous)
        // --------------------------------------------------

        flightState.update(
            bmpAltitude,
            millis());

        handleFlightStateEvent();

        // --------------------------------------------------
        // INA219 Update
        // --------------------------------------------------

        bool ina219Ok = ina219Sensor.update();

        float batteryVoltage = 0.0f;
        float current_mA = 0.0f;
        float power_mW = 0.0f;

        if (ina219Ok)
        {
            batteryVoltage =
                ina219Sensor.getBusVoltage_V();

            current_mA =
                ina219Sensor.getCurrent_mA();

            power_mW =
                ina219Sensor.getPower_mW();

            batteryMonitor.update(
                batteryVoltage);
        }
        else
        {
            batteryMonitor.update(
                0.0f);
        }

        updateBatteryEvents();

        mavBatteryVoltage = batteryVoltage;
        mavCurrent_mA = current_mA;
        mavBatterySoc = batteryMonitor.getPercentage();
        mavBatteryConnected = batteryMonitor.isConnected();

#if GPS_ENABLED

        // --------------------------------------------------
        // GPS Update
        // --------------------------------------------------

        bool gpsDetected = gps.isDetected();
        bool gpsFix = gps.hasFix();

        events.updateGpsState(
            gpsDetected,
            gpsFix);

        reportGpsHealth(
            gpsDetected,
            gpsFix);

        double latitude = gps.getLatitude();
        double longitude = gps.getLongitude();

        float gpsAltitude = gps.getAltitude();
        float gpsSpeed = gps.getSpeed();

        // --------------------------------------------------
        // GPS Speed Deadband
        // --------------------------------------------------

        if (fabs(gpsSpeed) < GPS_SPEED_DEADBAND_KMH)
        {
            gpsSpeed = 0.0f;
        }

#else

        bool gpsDetected = false;
        bool gpsFix = false;

        double latitude = 0.0;
        double longitude = 0.0;

        float gpsAltitude = 0.0f;
        float gpsSpeed = 0.0f;

#endif

        // --------------------------------------------------
        // Capture GPS Reference Altitude and Home Position
        // --------------------------------------------------

        if (gpsFix && !gpsReferenceCaptured)
        {
            gpsReferenceAltitude = gpsAltitude;
            bmpAltitudeAtReference = bmpAltitude;
            gpsHomeLatitude = latitude;
            gpsHomeLongitude = longitude;
            gpsReferenceCaptured = true;

            Serial.print("[INFO] GPS reference altitude captured: ");
            Serial.print(gpsReferenceAltitude, 1);
            Serial.println(" m");

            // Send HOME_POSITION once, as soon as the reference
            // point is captured on the first GPS fix.
            mavlink.sendHomePosition(
                gpsHomeLatitude,
                gpsHomeLongitude,
                gpsReferenceAltitude);

            homePositionSent = true;
            lastHomePosition = millis();
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

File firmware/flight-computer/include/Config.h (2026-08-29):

#pragma once

// =====================================================
// System Information
// =====================================================

#define SYSTEM_NAME                    "RocketOS"
#define SYSTEM_VERSION                 "0.15.0"

// =====================================================
// Installed Modules
// =====================================================

#define BMP388_ENABLED                 true
#define GPS_ENABLED                    true
#define SD_LOGGER_ENABLED              true

#define SYSTEM_HEALTH_ENABLED          true
#define EVENT_LOGGING_ENABLED          true
#define BUFFERED_LOGGING_ENABLED       true

#define LORA_ENABLED                   false
#define INA219_ENABLED                 false

// =====================================================
// GPS Configuration
// =====================================================

#define GPS_UART_BAUDRATE              38400

#define GPS_RX_PIN                     16
#define GPS_TX_PIN                     17

// Local time offset from UTC
#define UTC_OFFSET_HOURS               2

// Ignore GPS speed values below this threshold.
// Helps eliminate GPS noise when the device is stationary.
#define GPS_SPEED_DEADBAND_KMH         3.0f

// Time to wait during startup for GPS FIX before using fallback filename.
#define GPS_FIX_TIMEOUT_SECONDS        30

// =====================================================
// BMP388 Configuration
// =====================================================

#define BMP388_I2C_ADDRESS             0x77

// =====================================================
// SD Card Configuration
// =====================================================

#define SD_CS_PIN                      5

// SD usage monitoring thresholds
#define SD_USAGE_WARNING_PERCENT       80
#define SD_USAGE_CRITICAL_PERCENT      95
#define SD_USAGE_FULL_PERCENT          99

// =====================================================
// Logging Configuration
// =====================================================

#define LOG_INTERVAL_MS                1000

#define CSV_DECIMAL_PLACES             2

// Number of telemetry records stored in RAM if SD writing fails.
// This provides short-term protection against temporary SD write failures.
#define LOG_BUFFER_SIZE                100

// =====================================================
// GPS Logging Configuration
// =====================================================

#define USE_LOCAL_TIME_FOR_LOGS        true

#define FALLBACK_TO_BOOT_FILENAME      true

// =====================================================
// System Health Configuration
// =====================================================

// How often the system health status is printed to Serial.
#define HEALTH_PRINT_INTERVAL_MS       10000

// Timeout thresholds for detecting stale module activity.
#define GPS_DATA_TIMEOUT_MS            5000
#define BMP_DATA_TIMEOUT_MS            3000
#define SD_WRITE_TIMEOUT_MS            5000

// =====================================================
// POST Configuration
// =====================================================

#define HALT_ON_BMP388_FAIL            true
#define HALT_ON_SD_FAIL                true
#define HALT_ON_GPS_FAIL               false

// =====================================================
// Event Logging Configuration
// =====================================================

#define EVENT_LOG_FILE_NAME            "/events.log"

// =====================================================
// Debug Configuration
// =====================================================

#define PRINT_TELEMETRY_TO_SERIAL      true
#define PRINT_HEALTH_TO_SERIAL         true

// Runs a synthetic flight profile through the
// FlightStateMachine at boot instead of normal operation.
// Set to 0 for normal flight.
#define FLIGHT_SIMULATION_MODE 0

// =====================================================
// Buzzer Configuration
// =====================================================
#define BUZZER_ENABLED true
#define BUZZER_PIN 25

// =====================================================
// DS18B20 External Thermometer Configuration
// =====================================================
#define EXT_THERMOMETER_ENABLED   true
#define EXT_THERMOMETER_PIN       4

// =====================================================
// Serial Flight Profile Replay
// =====================================================
//
// Development / hardware-in-the-loop mode.
// When enabled, altitude samples are received over USB serial
// and replayed through the FlightStateMachine.
//
// IMPORTANT:
// This mode is intended for bench testing only.
#define SERIAL_PROFILE_REPLAY_MODE 0

// Safety flag for future actuators.
// Keep disabled by default.
#define SERIAL_REPLAY_ALLOW_ACTUATORS 0
#define SERIAL_REPLAY_VERBOSE 0

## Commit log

2026-07-25 Chore: remove KiCad lock file
2026-07-25 Chore: add ro*t gitignore and remove KiCad lock *ile
2026-07-25 Chore: remove KiCad backup files
2026-07-25 Chore: update root gitignore for KiCad files
2026-07-25 Docs: add INA219 power monitoring and battery architecture4
    [FlightTelemetry.kicad_sch]
2026-07-25 Docs: replace v0.8.2 schematic with Sprint 9 power architecture
2026-07-25 Docs: update wiring diagram to Sprint 9 power architecture
2026-07-25 Docs: add Sprint 9 power architecture and INA219 integration
2026-07-25 Docs: modify readme.md schematic v 0.9.0 naming typo
2026-07-25 Docs: add Sprint 9 power architecture and real hardware prototype
    [FlightTelemetry.kicad_sch]
2026-07-25 Docs: add Sprint 9 power architecture and real hardware prototype- Added real hardware prototype photo- Added INA219 hardware documentation- Added LiPo 4S power architecture- Added MP1584 power regul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
2026-07-26 Feat: add battery monitor and battery state detection- Added battery connection detection- Added battery percentage estimation- Added battery state monitoring- Added battery disconnect handling- Inte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
2026-07-26 Docs: update README and banner for v0.9.1 battery monitoring release
2026-07-26 Feat: add battery telemetry to CSV logging
2026-07-26 Feat: complete Sprint 9 battery monitoring and event system
2026-07-26 Chore: revert incomplete MAVLink integration
    [main.cpp]
2026-07-26 Feat: add MAVLink GPS, battery and global position telemetry
2026-08-02 Fix BATTERY_STATUS pack voltage: voltages_ext must be 0 for unused cells
2026-08-02 Sprint 11.4 - Flight instrumentation: VFR_HUD, GLOBAL_POSITION_INT, battery voltage fix and MAVLink speed deadband
    [main.cpp]
2026-08-08 Sprint 11.6 - HOME_POSITION: home reference sent on first GPS fix, Distance to Home validated in QGroundControl
    [main.cpp]
2026-08-08 Sprint 12 - Flight simulation validated on ESP32 hardware
2026-08-08 Update schematic v0.13.0 - buzzer and DS18B20 external thermometer
2026-08-09 Sprint 13a - DS18B20 external thermometer integrated (serial output)
    [FlightTelemetry.kicad_sch]
2026-08-09 Sprint 13a - DS18B20 external temperature added to CSV log (15 columns)
2026-08-09 Sprint 13a - Buzzer patterns, DS18B20, flight_state CSV, altitude reference fix
    [main.cpp]
2026-08-16 Sprint 14 - add flight profile replay tests
    [estes_c6.csv, low_apogee.csv, midpower_machdip.csv]
2026-08-16 Sprint 14 - add flight profile replay testing framework
2026-08-16 Sprint 14b - add serial flight profile replay mode
    [midpower_machdip.csv]
2026-08-23 correct power supply in schematic and physical considerations
2026-08-28 fix(battery): migrate battery monitor from 4S to 2S
2026-08-29 docs: update Mk1 baseline and add Power Deck v0.1
    [FlightTelemetry.kicad_sch, Power_Deck_v0.1.kicad_pcb, Power_Deck_v0.1.kicad_sch]
2026-08-29 fix(sd): track runtime logger state
    [main.cpp]
2026-08-29 chore: rename project to RocketOS
    [FlightTelemetry.kicad_sch]
2026-08-29 chore: reorganize KiCad hardware sources
    [FlightTelemetry.kicad_pcb, FlightTelemetry.kicad_sch, Power_Deck_v0.1.kicad_pcb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]
2026-08-29 feat(power-deck): complete v0.1 schematic
    [Power_Deck_v0.1.kicad_sch]
2026-10-10 feat(firmware): migrate flight computer to ESP32-S3
2026-10-10 chore(firmware): add ESP32-S3 hardware identification test
2026-10-10 feat(hardware): add Mk1 longitudinal PCB designs
2026-10-10 docs: update README for Mk1 prototype baseline
2026-10-11 fix(hardware): resolve Mk1 I2C address collision
